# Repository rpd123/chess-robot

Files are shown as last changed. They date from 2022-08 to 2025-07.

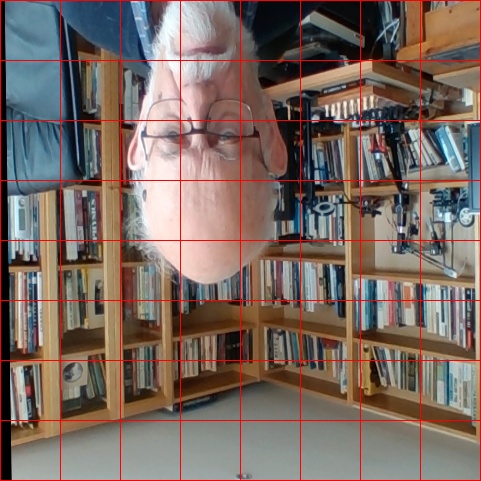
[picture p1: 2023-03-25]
versiongui/images/redlines.jpg

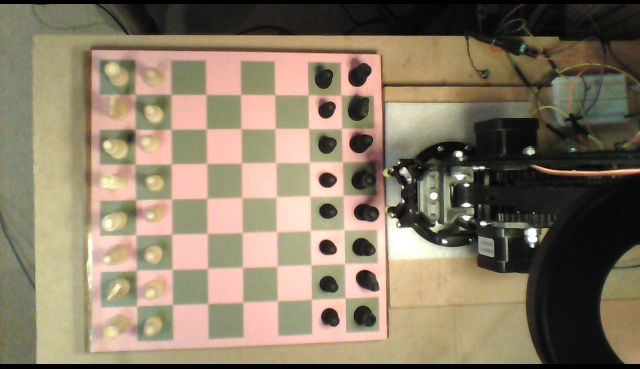
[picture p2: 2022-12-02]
version2/images/1.jpg

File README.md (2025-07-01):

# chess-robot  
  
For the Android/GUI version see the instructions in the versiongui directory.
    
3D printed chess robot, Python code for Raspberry Pi, other Linux or Windows PC. New users should use version 2.

Install Stockfish engine, Python 3, python-pip, espeak

pip install pyserial  
pip install psutil  
pip install numpy  
pip install opencv-python  
pip install stockfish  
pip install pyttsx3  

Run CBint.py from Thonny or elsewhere.

The camera should be positioned directly over the centre of the chess board and lined up pretty well. Then camera calibration asks you to click on the four corners of the playing area of the chessboard (on the image), and you are shown the result. Click them in the order requested. (The robot arm should not be in the way, and all the pieces must be in their correct starting positions). By "playing area" we mean the chessboard squares, NOT including any external margin).

The calibration is remembered even if all systems are shut down, so if the robot, board and camera have not been moved, recalibration can optionally be avoided when a new game is started

The camera should be at least 56 cm above the board. Square size 3.4 cm. Tallest piece: 5.5 cm. The image of a piece should not fall across an adjacent square.

Calibrating the Cartesian robot arm: The lower strut must be vertical and the upper strut horizontal and coming out straight over the board.

Code configuration: You will need to check squaresize, axistorow8, etc. in robotmove.py. Check the declarations in CBstate.py.

Axistorow8 is the distance in mm horizontally along the y coordinate, between the robot’s vertical axis and the centre of row 8. 

The RPi or PC is connected to the Arduino by a USB A/B cable (printer cable). Or alternatively via Bluetooth (not BLE), using an HC-05 Bluetooth module.

Both USB and IP cameras are supported. Calibration for fish-eye distortion is provided, and is more likely to be needed for IP cameras. USB cameras are often OK without it.

Arduino code is at https://github.com/rpd123/Arduino-Firmware 
  
===  
Version1-old only:  
pip install pillow
pip install psutil  
On RPi install fswebcam, aplay

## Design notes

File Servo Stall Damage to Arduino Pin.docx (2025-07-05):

# Servo Stall Damage to Arduino Pin

https://g.co/gemini/share/499b7cfb72a6

Created with 2.5 Pro 4 July 2025 at 16:27 Published 4 July 2025 at 16:36

Is it possible that servo stalling might broke the pin in my arduino mega connected to ramps 1.4 to d4 pin

Google Search

Google Search

Yes, it is possible, though not guaranteed, that a stalling servo could damage the D4 pin on your Arduino Mega connected to a RAMPS 1.4 board. The damage is less likely to be from a direct overcurrent on the signal pin itself, but rather from electrical side effects of the stall.

Here's a breakdown of the potential failure mechanisms:

### How a Stalling Servo Can Damage Your Arduino Pin

When a servo motor stalls, it attempts to draw a much larger current than it does during normal operation. This high current draw, which can be several amps for a standard servo, is the primary source of potential damage. While the servo's power and signal lines are separate, a stall can create conditions that harm the delicate microcontroller pin.

- Ground Potential Difference: This is the most likely culprit. The high stall current flowing through the ground wire of the servo's power supply can cause a significant voltage drop along that ground path. This means the "ground" reference at the servo could be at a higher voltage than the Arduino's ground. This difference in ground potential can expose the Arduino's D4 pin to a voltage level outside its safe operating range, leading to damage. The absolute maximum rating for an Arduino Mega's I/O pin is 40mA, and they are designed to operate at 5V. A sudden surge or a sustained voltage difference can easily exceed these limits.
- Internal Servo Failure: A prolonged stall can cause the servo's internal electronics to overheat and fail. In a catastrophic failure, it's possible for the servo's internal wiring to melt and create a short circuit between the power and signal lines. If the higher voltage from the servo's power supply were to be shorted to the signal line, it would send a damaging amount of current and voltage directly to the Arduino's D4 pin.
- Electrical Noise: The high and erratic current draw of a stalling servo can introduce significant electrical noise onto the power and ground lines. This noise can sometimes manifest as voltage spikes that, if they propagate to the signal line, could be high enough to damage the Arduino pin's sensitive input/output circuitry.

### How the RAMPS 1.4 Connection Plays a Role

The RAMPS 1.4 board provides separate power inputs for the motors and the logic circuits. The servo headers on the RAMPS board, including the one for D4, have pins for signal, 5V power, and ground.

- Shared Power (More Risky): If your servo is being powered directly from the Arduino's onboard 5V regulator (which is common if the D1 diode is installed on the RAMPS board and you are not using an external 5V power supply for the servos), a stall is particularly dangerous. The Arduino's regulator is not designed to handle the high current demand of a stalled servo, which can lead to a voltage drop across the entire 5V rail, affecting the Arduino's operation and increasing the risk of damage to the I/O pins.
- Separate Power (Less Risky): If you are using a dedicated, external power supply for the servos connected to the VCC and ground pins of the servo headers, the risk to the Arduino pin is reduced but not eliminated. The ground potential difference and internal servo failure scenarios can still occur.

### How to Prevent Damage

To protect your Arduino Mega from a stalling servo, consider the following precautions:

- Use an External Power Supply for Servos: Never power more than a single, small servo from the Arduino's onboard 5V regulator. Use a sufficiently rated external power supply for your servos.
- Ensure a Solid Ground Connection: Use thick wires for your ground connections and ensure they are all securely connected to a common ground point to minimize ground potential differences.
- Implement Stall Detection: In your code, you can monitor the servo's position or the current draw (with additional hardware) to detect a stall and cut power to the servo if it doesn't reach its target position within a certain time.
- Add a Current Limiting Resistor: Placing a small-value resistor (e.g., 100-220 ohms) in series with the servo's signal line can offer a degree of protection against small voltage spikes, though it won't protect against a major short circuit.

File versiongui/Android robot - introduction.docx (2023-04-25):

# Chess Robot, 3D-Printed Using Android Phone and Arduino

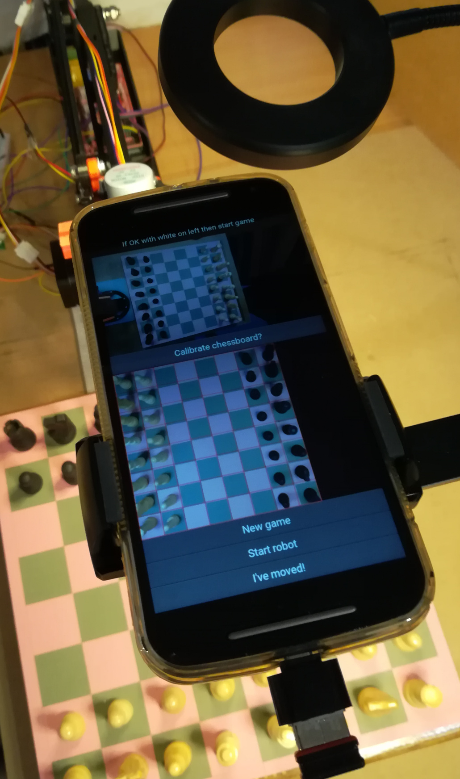
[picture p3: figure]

## Introduction

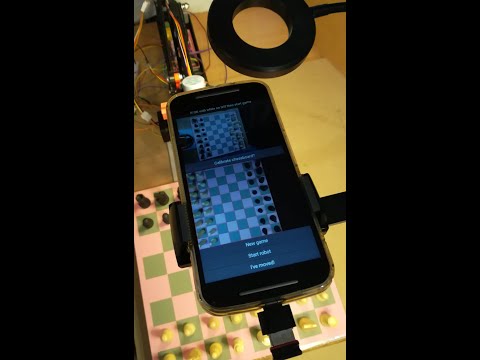
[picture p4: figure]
3D Printed Chess Robot using Android Phone

This chess robot can beat any human!

I previously made a similar 3D-printed chess robot (https://projecthub.arduino.cc/ricpd/3df8bfc4-811c-4ca7-b46a-600d62875669) which makes use of a Raspberry Pi or Windows. That version needs a USB camera, a display screen and keyboard as well as an RPi or Windows processor. Whereas the version described here just needs a discarded Android phone. The phone's camera, microphone and touch screen are used, and the phone is connected to an Arduino via Bluetooth - so no wires come out of the phone.

## Supplies

3D printer

Stepper motor NEMA 17 (x3)

Stepper motor driver board A4988 (x3)

Stepper motor 28BYJ-48 (for grabber)

Stepper driver board ULN2002

Arduino Mega 2560

Ramps 1.4

USB lights (x2)

Spare Android phone (!)

Bluetooth module HC-05

Stand for lights and phone

Wireless mouse and dongle (for chessboard calibration)

Micro USB (or USB-C) OTG to USB Adapter (ditto)

Power supplies

## Requirements

The chess-playing code is written in Python and runs on an Android phone. The code for inverse kinematics and driving the motors runs on an Arduino Mega 2560. A Ramps 1.4 board is attached to the Arduino

The 3D-printed robot is built using STL files.

You will also need a table, lighting and something to hold the phone above the board. And of course, chess pieces and a chessboard. I describe all these things in more detail in the subsequent steps

## How It Works

It works like this:

The human, playing white, makes a move. This is detected by the visual recognition code on the phone. The robot then ponders and then makes its move.

And so on...

Perhaps the most novel thing in this robot is the code for move recognition.

Because the human's move is recognised by a vision system, no special chess board hardware (such as reed switches, or whatever) is needed.

## The Hardware Build

The 3D printer files for the robot are freely available as specified by ftobler here (https://www.thingiverse.com/thing:1718984). Modifications for a longer arm are here (https://www.thingiverse.com/thing:4364030). This is required in order to reach the far corners of the chess board.

We built the cartesian robot (https://projecthub.arduino.cc/ricpd/3df8bfc4-811c-4ca7-b46a-600d62875669), but the SCARA robot (https://projecthub.arduino.cc/ricpd/8bd1b9cd-a719-414a-b0e5-128ca6b6f264) should also work.

In the previous builds we used a special mini-gripper, but this time we used a gripper based on the original ftobler gripper but we modified the files to have longer and thinner fingers, which makes it more suitable for picking up chess pieces. All the STL files for the gripper are here (https://github.com/rpd123/chess-robot/tree/main/stepper%20gripper). The mini-gripper worked with a mini servo motor, but this time we followed ftobler in using a 28BYJ-48 stepper motor.

The stepper motors give very high precision and repeatability.

However, there is a problem with the gripper stepper motor in that when it grips it thinks it has moved to the target position when it hasn't. So when the gripper is opened again it opens to far, and then when closed it doesn't close enough. This is resolved by putting in two screws as endstops for the open position.

The code supports Bluetooth (not BLE), using an HC-05.

The RX output from the HC-05 is connected via a voltage divider to D16 on AUX-4.

The TX output is connected directly to D17 on AUX-4.

https://osoyoo.com/2016/07/03/reprap-3d-printer-circuit-connection-graph/

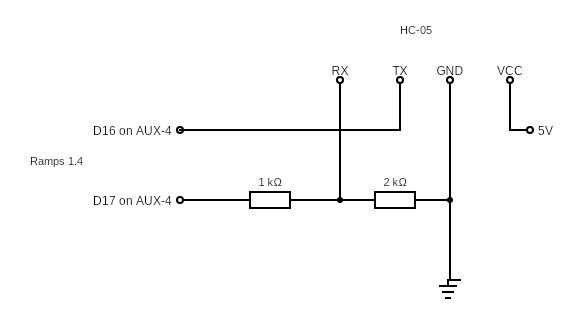
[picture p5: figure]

## The Software Which Moves the Robot

## All the Android code is written in Python 3, and runs on Pydroid 3. The Python files, together with instructions for installing and running can be found here (https://github.com/rpd123/chess-robot/tree/main/versiongui). (This includes instructions for installing Pydroid 3).

So, we then have code which will move pieces, take pieces, castle, support en passant, and so on.

There is a choice of chess engines. If your phone is running Android 7, or if it is rooted, then Stockfish can be used.

Stockfish can beat any human! It is one of the strongest chess engines in the world. It is also much stronger than the best human chess grandmasters.

If your phone is not rooted and it is running a version of Android higher than 7, then Sunfish can be used. It is a simple chess engine - however, it plays at ratings above 2000 at Lichess.

I use some code from chessfortherapy.co.uk to validate the human's move and interact with the chess engine. My code for recognising the human's move and moving the robot arm interfaces with that.

On the Arduino, inverse kinematics code is used in order to move the various motors correctly such that chess pieces can be moved. This code is based on code which ftobler wrote, and can be found via the link above.

## The Software for Recognising the Human's Move

This is similar to the code that I wrote for my previous Cartesian chess robot so please see the description there.

## Other considerations

## The algorithms work best if the chessboard has a colour that is a long way from the colour of the pieces! In my robot, the pieces are off-white and matt black, and the chess board is hand-made using a colour printer onto thin card. It can be seen in the video.

The chessboard should well-lit and evenly lit with minimal shadows from the chess pieces. Light should not be reflected back into the camera from the board or pieces. A sturdy table is needed.

Instructions for calibrating the chessboard and the robot can be found via the first link in the previous section.

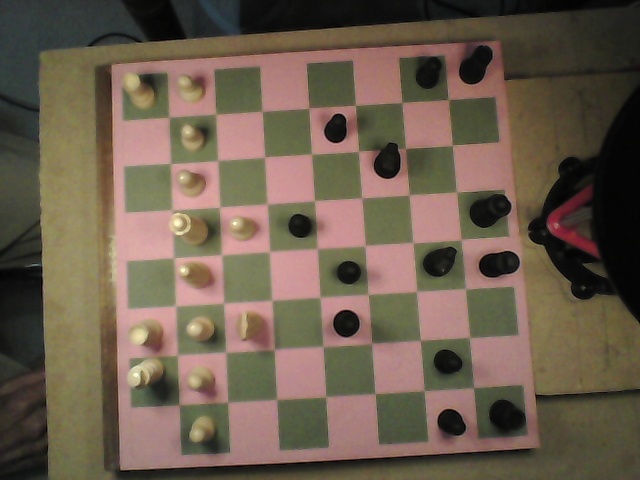
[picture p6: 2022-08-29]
versiongui/images/1copy.jpg

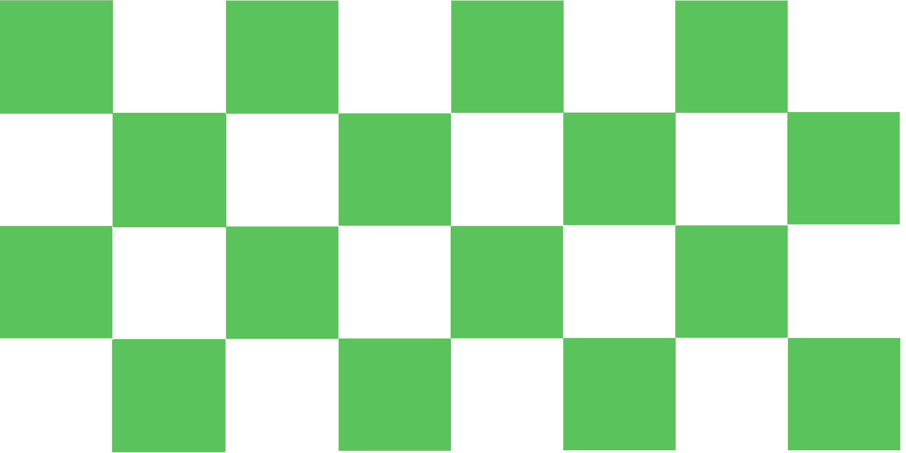
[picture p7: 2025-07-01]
chessboardprint.png

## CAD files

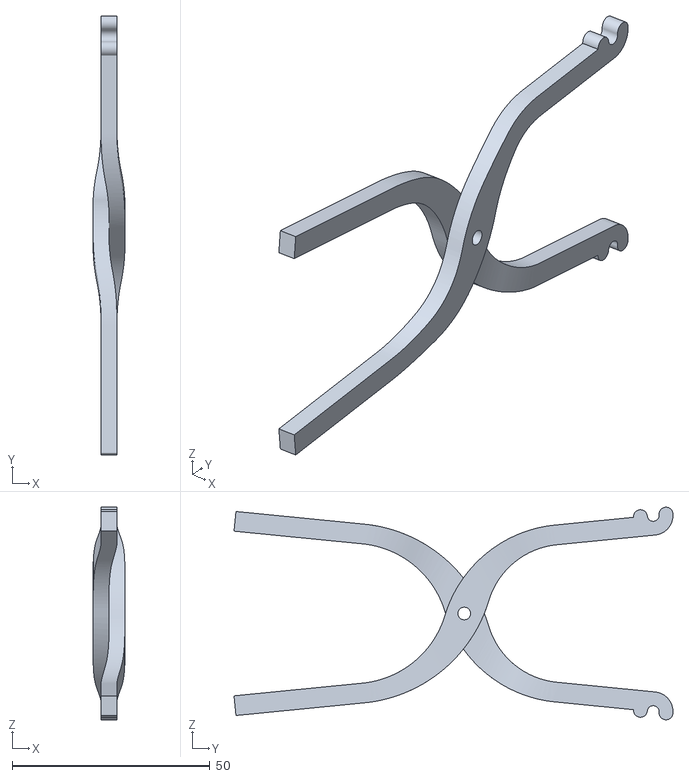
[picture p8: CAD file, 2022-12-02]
another gripper/newgripper-gripper001.0.stl
8.00 x 111.0 x 53.8

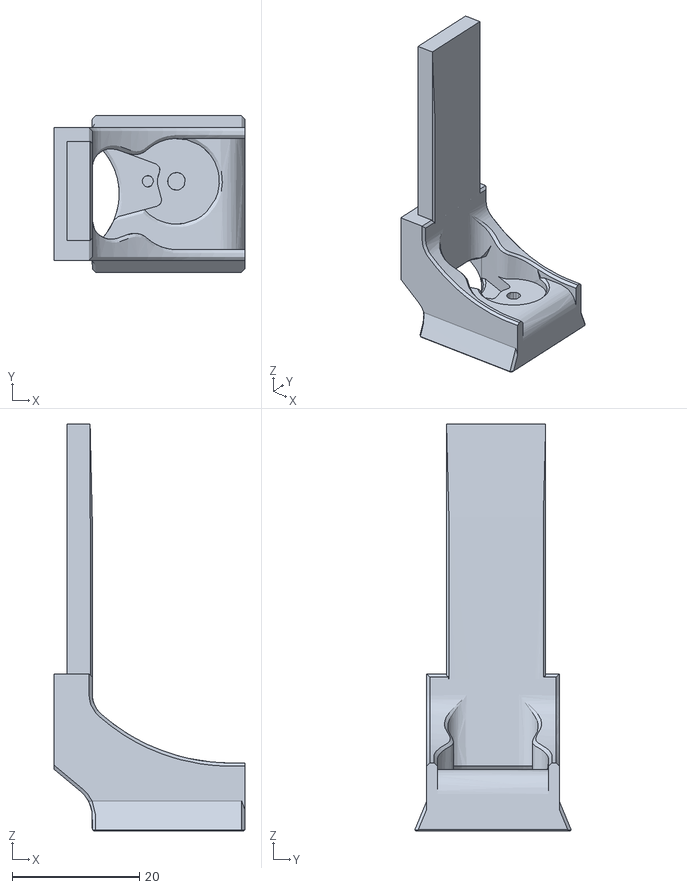
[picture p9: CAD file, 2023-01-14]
stepper gripper/gripperFinger3.stl
30.0 x 24.6 x 64.0

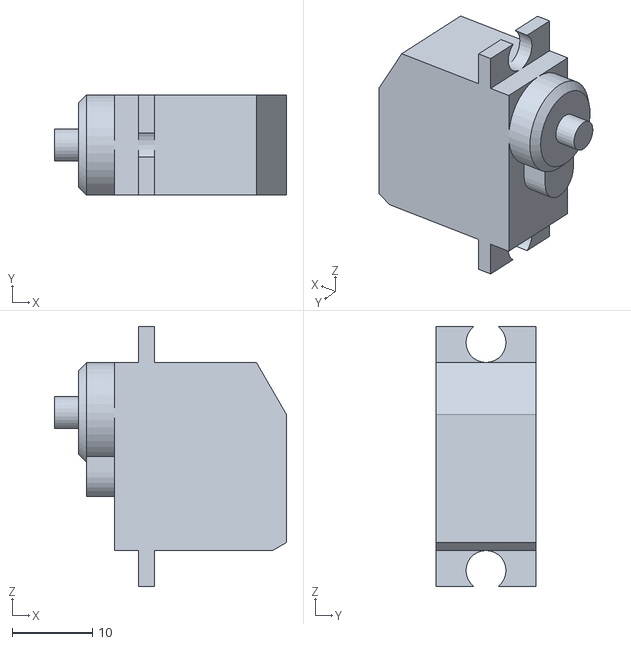
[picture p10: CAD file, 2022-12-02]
another gripper/newgripper-gripper001.1.stl
29.0 x 12.5 x 32.5

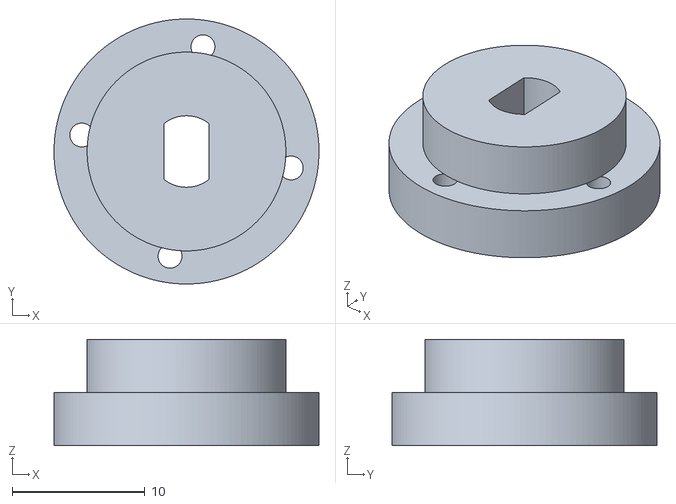
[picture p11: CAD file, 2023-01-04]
stepper gripper/gripper_shaft.stl
20.0 x 20.0 x 8.00

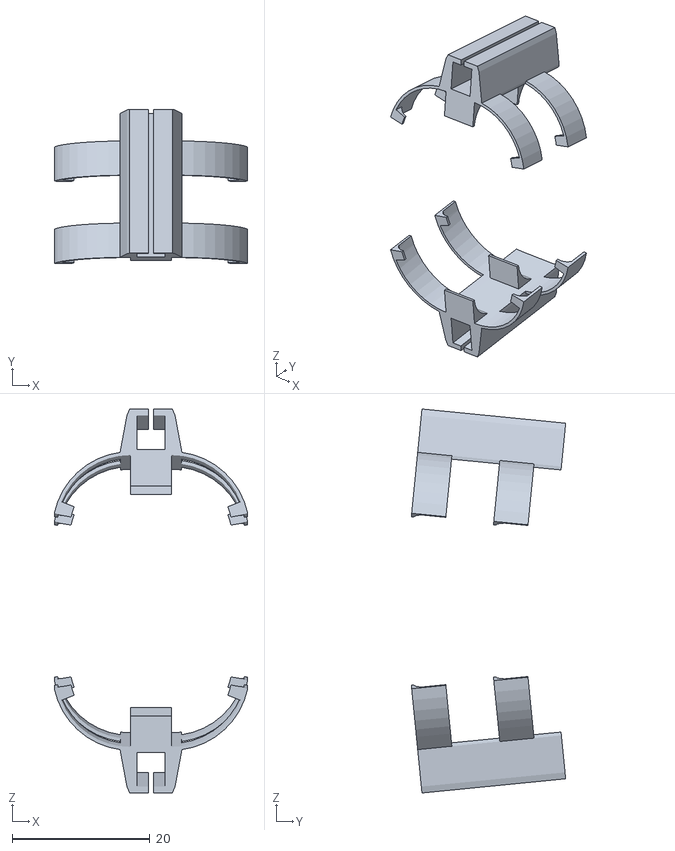
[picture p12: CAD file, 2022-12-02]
another gripper/newgripper-gripper001.3.stl
28.1 x 22.4 x 55.8

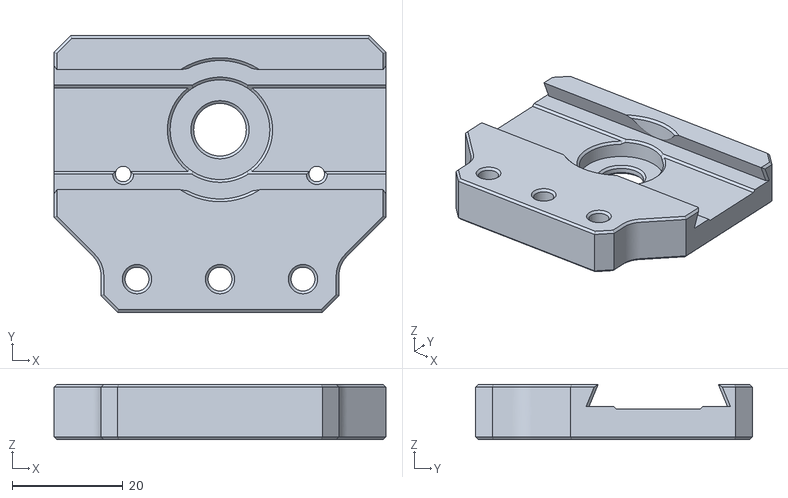
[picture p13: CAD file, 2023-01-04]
stepper gripper/gripperBase_by_ftobler.stl
60.0 x 50.0 x 10.0

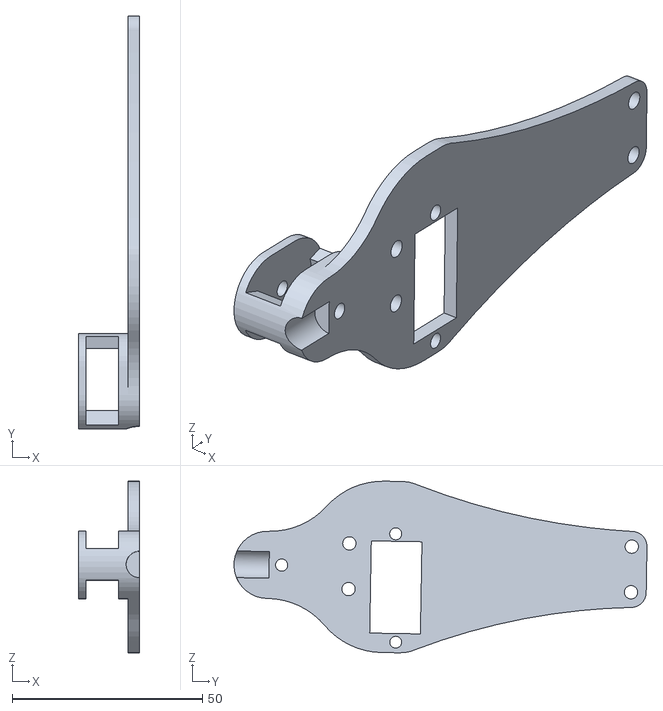
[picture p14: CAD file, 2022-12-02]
another gripper/newgripper-gripper001.4.stl
16.0 x 108.6 x 45.2

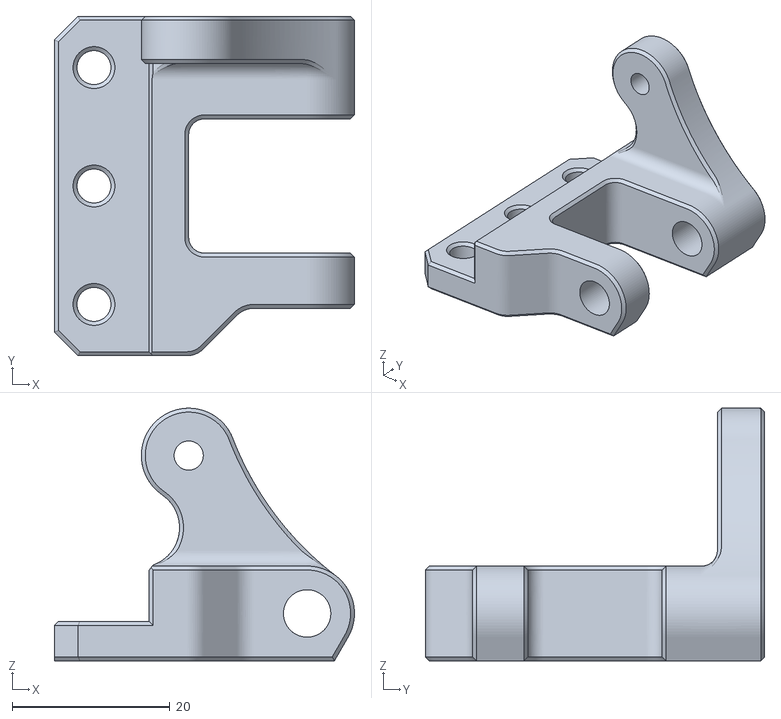
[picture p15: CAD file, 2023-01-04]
stepper gripper/manipulator.stl
38.0 x 43.0 x 32.0

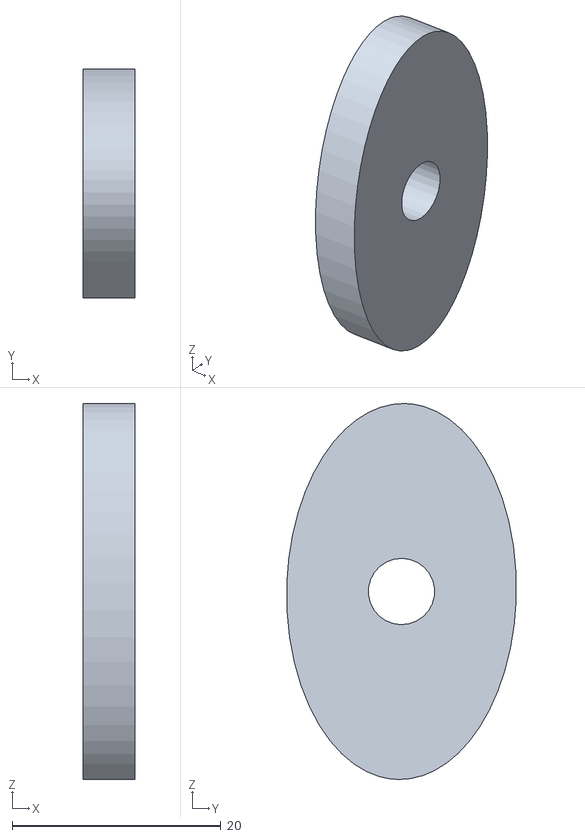
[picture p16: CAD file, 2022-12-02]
another gripper/newgripper-gripper001.2.stl
5.00 x 22.0 x 36.0

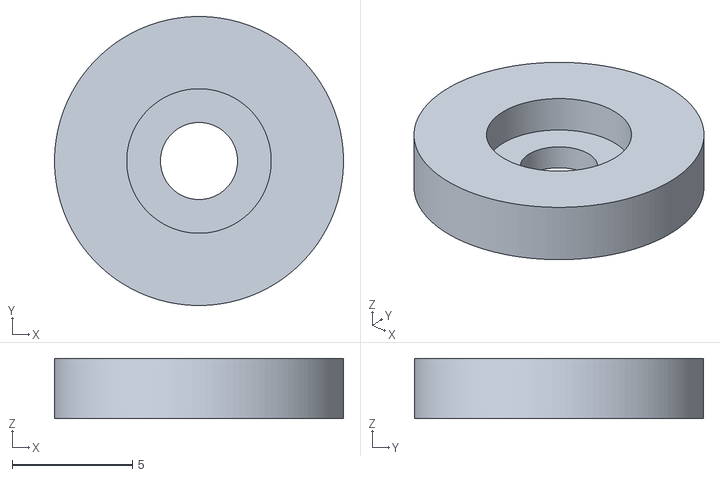
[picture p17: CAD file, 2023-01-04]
stepper gripper/gripper_screw_secure.stl
12.0 x 12.0 x 2.50

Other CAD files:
stepper gripper/gripperHolePlate.stl

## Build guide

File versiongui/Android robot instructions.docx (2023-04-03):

# Android robot instructions

## Installation:

Install from Google Play Store:

Pydroid 3
Pydroid repository plugin
Pydroid Permissions Plugin
Stockfish Engines OEX (if using Stockfish)

Installing Pydroid 3 will automatically install Python3

Open Pydroid 3 and choose “Pip” from the menu. In there you can install Python modules by merely typing their names:

kivy
pyserial
psutil
numpy
opencv-python
plyer

Arduino files are at
https://github.com/rpd123/Arduino-Firmware

After downloading to the PC, use the Arduino IDE to upload them to the Arduino. But before that …

Change two lines in an Arduino library file, which in my case is at:

ProgramFiles(x86)\Arduino\hardware\arduino\avr\cores\arduino\HardwareSerial.h

A couple of lines with buffer size 64 – change to

#define SERIAL_TX_BUFFER_SIZE 128

#define SERIAL_RX_BUFFER_SIZE 128

Pair the phone and the HC-05 if not already paired

Download files for the phone from:

https://github.com/rpd123/chess-robot/tree/main/versiongui

Configuration

Change configuration variables in CBstate.py, robotmove.py and Arduino config.h as appropriate.

Line 5 of config.h should be changed to
#define SERIALX Serial2

when Bluetooth is used.

## Electronics notes

HC-05

The RX output from the HC-05 is connected via a voltage divider to D16 on AUX-4 on the RAMPS.

The TX output is connected directly to D17 on AUX-4.

https://osoyoo.com/2016/07/03/reprap-3d-printer-circuit-connection-graph/

Voltage divider example (Ignore connections to Arduino):

https://electronics.stackexchange.com/questions/280500/why-do-you-have-to-use-a-voltage-divider-with-hc-05-bluetooth-module-arduino

Connections to steppers

Shank1 goes from the shoulder to the elbow, and shank2 goes from the elbow to the gripper.

Connect:

X controller to motor which moves shank2

Y controller to motor which moves shank 1

Z controller to motor which moves the robot vertically

In this diagram
https://github.com/rpd123/community_robot_arm/blob/master/Assembly%20%26%20Control%20Guides/Wiring%20Guide/wiring-lower%20motor.jpg

Controllers are X, Y, Z from left to right.

Note: in this context X, Y, Z refer to motors, not cartesian coordinates.

## Running

Hide the on-screen navigation buttons (if any). (See below).

Have the OTG and wireless mouse dongle in

Open Pydroid3, open main.py and press the yellow button. (Note: NOT CBint.py)

Then you should see “Let’s play chess” at the top of the screen.

This area will be used for messages. The phone is likely to be slow, so at each stage, wait for a new message.

The phone should be positioned directly over the centre of the chess board and lined up fairly well. (The robot arm should not be in the way, and all the pieces must be in their correct starting positions).

Ensure that you can see the whole of the chessboard in the video view. Click on the “Calibrate chessboard” button. A static image will appear below, and a new message.

Using the mouse, click on the corners of the playing area starting at the bottom left. (Note: NOT top left). By "playing area" we mean the chessboard squares, NOT including any external margin.

You should then see the redlines image.

Ensure that you have power to the RAMPS.

Click on Start game, and wait … until it says Game Started.

Click on Start robot and wait.

That button text will change to say “Switch on steppers” Do that.

Button text will change to “Adjust ROBOT placement”. Adjust position of robot base if needed, then press button.

Make a move then press “I’ve moved”

Further info

Once the code is up and running, steppers are on and robot is in home position:

At any time you can put the chess pieces back to the opening position and
Optionally re-calibrate chessboard
Optionally re-calibrate robot
Click on New Game
Then make move

In particular, you can start a new game without re-calibrating the chessboard and without re-calibrating the robot.

You can re-calibrate the chessboard or the robot if the pieces are in the opening position.

If Pydroid is not running
Ensure chess pieces are in the opening position
Open Pydroid, open and run main.py
Optionally calibrate chessboard
Click on New Game
start and calibrate the robot
make move

When the program is closed, the connection to the robot is irretrievably lost, so the robot always has to be re-calibrated when starting from scratch. (But the chessboard does not have to be re-calibrated).

The calibration of the chessboard is retained, so as long as the board, robot and phone have not moved, it is not necessary to re-calibrate the board

Hiding on-screen navigation buttons

This can usually be done via Settings:
https://support.google.com/android/answer/9079644?hl=en

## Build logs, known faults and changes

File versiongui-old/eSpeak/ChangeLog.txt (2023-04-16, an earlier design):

espeak 1.48.04  06.04.2014

Corrections to languages en, nl, ta (rules, list, and dict files).
No other changes from version 1.48.03. No change to program, phoneme
data, or other languages.

espeak 1.48.03  04.04.2014

Fix bug, use of the command-line  "espeakedit --compile" produced phoneme data
in which vowels started at full amplitude instead of gradual increase.

Fix bug:  SSML <break time=""> with values greater than 23 seconds were ignored
due to arithmetic overflow.

Phoneme definition files:
Added new function:  ChangeNextPhoneme().

Language changes include: da, en, fa, gu, hu, it, nl, pt, ta

Started new language: eu (Basque).

*_rules files:
Allow $p_alt1, $p_alt2, etc in pre-conditions.  The rule matches if the
characters before the current point in the word occur as an entry in the
*_list file with the corresponding $alt attibute.

Added condition $list.  This is similar to $p_alt etc, but examines
all words in the *_list file which don't have the $only attribute.

espeak 1.48.01  02.02.2014

*_rules files:
Added rule attribute $noprefix.  The rule is not used if a prefix has been removed from the word.

Windows:
Program changes to enable audio output from Windows DLL.

Language options: 
Added attribute 'dictdialect' to specify en-us voice for words marked with _^_EN.

Superscripts and subscripts are spoken as single letters and numbers during normal speech, and with "superscript" and "subscript" also spoken when spelling.

API: Change function call espeak_TextToPhonemes().

Klatt synthesizer: Fix parallel formant parameters.

Language changes include:
af, an, da, en, fa, ga, gu, hu, hy, it, ml, nl, ta, ur, vi. 

espeak 1.47.10  30.04.2013
  Data change only.
  Revert 't' sound in Spanish to version 1.47.07.

espeak 1.47.09  29.04.2013
  Bug fix (lookup in *_list occasionally found the wrong word).

espeak 1.47.08  26.04.2013

Automatically generate character names for subscript and
superscript characters.

Use internal ctype data for character codes up to U+024F.

Add API function  espeak_TextToPhonemes().

Add test language az, Azerbaijani.

espeak 1.47.07  18.04.2013
Language data changes only.

espeak 1.47.06  15.04.2013
Bug fix for names of non-ascii digits.

RISC OS version:
  Fix for systems which have 44010Hz but not 22050Hz audio.
  Now runs OK in ARMv7 mode.

espeak 1.47.04  02.04.2013

Bug fixes.

Phoneme definitions: add conditions prev2PhW(), next3PhW().

Added language: ms (Malay)

Command line:
  --voices=<directory>  lists the voices in the specified subdirectory.

espeak 1.47.03  21.03.2013

Bug fixes.

espeak 1.47.01  18.03.2013

Added languages:
  an  Aragonese.
  fa  Farsi.
  ga  Irish.
  lt  Lithuanian.
  pa  Punjabi.

Many language improvements, including American English, Danish, Dutch, Portuguese, Tamil.

Command-line program.  Added -version option.

Command-line program.  Added optional value to --ipa option.
  --ipa=1 adds a 'tie' character to link letters in a multi-letter phoneme name.
  --ipa=2 adds a zero-width joiner to link letters in a multi-letter phoneme name.

Command-line program. -X option now lists the names of attributes from *_list files.

Speak the names of Braille Dot characters, U+2800 to U+28FF.

Speak names of characters in some non-native alphabets.

Automatic switch to a different language for text in non-native alphabets.

Improved speaking of text from a non-native alphabet after automatically switching
to a different language voice.

Break words with characters from different alphabets into separate words.

Ignore soft-hyphen (U+00AD) in text.

Klatt vioices, improved nasal vowels.

espeak-data can be compiled using a different sample rate than the default
22050Hz.  eSpeak will then generate speech at that sample rate.

Change the structure of the espeak-data/voices directory to use subdirectories
for europe, asia, and others.

*_rules files.
  Add suffix option 'm' to allow multiplr suffixes to be removed from a word.

*_list files.
  Allow $text attribute when a text translation is given in a different alphabet.

Phoneme definitions.
  Add NOT operator in conditions.
  Add prevVowel() and nextPh2W() 
  Ignore UTF8-BOM sequence at the start of phoneme definition files.

espeakedit application.
  Use wxWidgets 2.8 on Linux.
  Use wxNotebook for prosody and vowel pages.
  Add an option to compile the phoneme data at a specified sample rate (uses the 'sox'
    program for the conversion of WAV file data).

espeak 1.46.01  22.Nov.2011

Added runtime detection of pulseaudio, with fallback to portaudio if pulse is not running.  Use build option "AUDIO=runtime" in the makefile.

Fixed crash on re-initializing libespeak.

SSML.  Commands such as <mark> and <prosody> were ignored if they were inside a multiword group (defined in *_list). Fixed.

SSML. Don't omit <marker> event for words which are recognized as pairs (such as "of the").

SSML: Keep the original voice variant across SSML xml:lang changes.

SSML: Use the original language sub-type (eg. en-sc) when SSML xml:lang changes to a compatible language.

SSML <emphasis>, increase volume for "strong" and "x-strong".

SSML Fix bug where </emphasis> was ignored at end of clause.

SSML: Fix problem where speed can get set to minimum after a <mark> tag.

SSML: Fixed bug where SSML voice change didn't remember an initially specified Klatt variant.

Mbrola:  Add support for voices:  vz1, mx1, mx2.

Mbrola:  Amplitude changes now apply also to mbrola voices.

Mbrola:  "voicing" attribute in mbrola voice files can be sued to adjust the loudness of the mbrola voice.

*_list:  $combine.  Don't combine with the next word if it uses a different language translator.

*_list: $dot attribute was ignored for multi-word entries.

Phoneme definition files. Phoneme programs. Added condition "isTranslationGiven" to test whether a phoneme has been specified explicitly for a word in *_list.

Lang=Hindi:  Suppress some [@] vowels.

Lang=Spanish, fix missing "y" in numbers such as "21".

Lang=EN-US: Don't add 'intrusive r' between phoneme [i@] and a following vowel.
lang=EN-US, distinguish phonemes [aI@] and [aI3] (compare "diet", "tired").

espeak 1.45.04  25.Apr.2011

Added language Malayalam (ml).

lang=de, Fixed important pronunciation error "sage" etc.

Don't speak punctuation names faster at high speeds.

lang=ml, recognise "virama + U+200d" (zero-width joiner) to indicte 'chillu' characters.

Fix problem of punctuation character announcement repeated at the start of the next sentence after speaking is stopped.

Fixed crash due to large numbers of box-drawing characters in text input.

Fixed mbrola phoneme translation of 't' sounds for US-English voices.

espeak 1.45.03  22.Mar.2011

lang=Turkish, fix pronunciation of suffixes, fix suffixes after names.

Windows: command option --stdout caused spurious 0x0d bytes to be included in speech output (CR/LF problem).

Fixed crash which could occur when a clause starts with a hyphen.

espeak 1.45.02  15.Mar.2011

Only use "sonic" speedup above 450 wpm.

lang=Turkish, fix bug, letter uppercase-I-dot was not recognized on Windows.

espeak 1.45.01  14.Mar.2011

Added languages:  Kannada (kn), Georgian (ka)

Many fixes for various languages, including
Danish, Dutch, English, French, German, Hungarian, Russian, Tamil, 

lang=German.  Revert to previous pronunciation of 'r' sounds (from before 1.44).
lang=Esperanto.  Change prosody.

Added "sonic" code (by Bill Cox) to increase the speed of speech after it has been generated by eSpeak.  This removes eSpeak's 450 speed limit.

Command-line options.
Recognize --  which means don't treat following arguments as options.
--help  also gives the path of the espeak-data directory.

SSML
Allow single as well as double quotes around strings.
Fix bugs in SSML "prosody rate".

Mbrola.  Look for Mbrola voices also at /usr/share/mbrola/xx/xx

Fixed bug where double .. was ignored.

Fixed bug in reporting word event lengths in callbacks.

Fixed bug in reporting marker event positions in callbacks, when non-ascii text.

Phoneme definitions.
New keyword "prevoice": always add murmer before a voiced stop, not only after a vowel.
Fixed bug in nextVowel() condition that caused crash.
Fixed bug is condition "isRhotic".

espeakedit.
Try "aplay" and then "play" to play sound.
Improved the Tools->Lexicon functions, which generate **_listx data from a list of words and their pronunciations.

espeak 1.44.04

Fix error in big-endian data conversion program, producing bad data.

Make geminated voiced stops (eg. [bb] ) longer at fast speeds.

Provide conditional compilation of the mbrola interface, define macro INCLUDE_MBROLA in speech.h

Mbrola: also look for mbrola voices in /usr/share/mbrola/voices

Pad TUNES and frame_t structures to a multiple of 4 bytes.

lang=da, Don't weaken unvoiced stops before pause.
lang=el, Remove final unstressed [a] if the next word starts with [a].
lang=pt, Change final [U] to [w] if next word starts with a vowel.

espeak 1.44.03

Fixes:
Lang=el, mk.  Was speaking words as individual letters.
Lang=pl.  Fix prounciation of 'ć' and 'ci'.
Fix crash in big-endian data conversion program.
Fix problem where changing voices reduces the speaking rate, at fast rates.

speak_lib.h:  add macro definitions for minimum, maximum, and normal speaking rate values.

espeak 1.44.01

Fix crash with very long numbers.
Speak very long numbers as individual digits.

Unpronouncable word check:
  Rules for unpronouncable initial letter sequences can now be defined in *_rules files.

  The unpronouncable word check now stops when an apostrophe is found.

Phoneme definitions:
  Optional second parameter to FMT() statement specifies a percentage amplitude.

  Added "ipa" statement to specify the IPA name for a phoneme if the default translation is not correct.

  Add phoneme "equivalents" tables, so that words can be spoken with foreign (eg English) prounuciation rules, but using local phonemes.

  New attributes:  flag1, flag2, flag3

  New attribute: nopause. Prevents the insertion of a short pause when this phoneme starts a word which follows a vowel.

  New conditions: isFlag1, isFlag2, isFlag3, isSibilant.

  New statement: InsertPhoneme()

Phonemes: improve syllablic [m-] [n-] [N-]

Mbrola:
  Command-line espeak and the libespeak library now call the mbrola program directly, rather than producing phoneme text which must be piped into mbrola.

  Added --pho command-line option to generate mbrola phoneme information (.pho data).

Phoneme output:
  Add --ipa command-line option to produce phonemes names using the International Phonetic Alphabet.

  Indicate language changes during phoneme output with: (en)  (fr)  etc.

-X command-line option: Show the matching of multiple-word entries in *_list files.

Speak sequences of letters and dots as individual letters and don't speak 'dot' (eg. "u.s.a").

Don't speak punctuation characters inside <audio> ... <audio/>.

Don't speak "dot" if an ellipsis is followed by a dot.

Vowelcharts:  Show the positions for multiple FMT() statements in a vowel phoneme definition.

*_rules: add attributes  $p_alt $p_alt2 $p_alt3,  $w_alt $w_alt2 $w_alt3

*_list:  add attributes:  $sentence, $atstart

klatt synthesizer: implement echo (defined in voice files).

espeakedit:
  Prosody display: Show stressed and secondary-stress syllables.

  Remember window size and position.

  Change the frame-length field from Spin Control to Text Control to allow better access from screen-readers.

Intonation:
  New file, 'phsource/intonation' to define 'tunes' which can be used from voice files.

  espeakedit: add Compile -> Intonation data

  Intonation: change the internal pitch unit to give finer control, and align with the values displayed in the espeakedit Prosody window.

Speed: Increase range to 80 to 450, with default=175.
Improve speaking at high speeds.

Language options: add an option to the Regressive Voicing option to de-voice the final consonant of words.

lang=ta, hi.  Letter-names for combining vowel characters are distinguished from stand-alone vowel characters by adding an initial click sound.

lang=en: Reduce consecutive unstressed syllables to 'diminished' stress, only in unstressed words.

lang=de: Change 'r' phoneme.

lang=es: Improve the rules for reducing 'b', 'd', 'g' to approximants [B] {D] [Q].

Language improvements include: Danish, Dutch.

espeak 1.43.03  (bug fixes)

Fix crash when embedded control codes are followed by numbers of 5 or more digits.
Fix lang=hu,  First character of an abbreviation is missed after an ordinal number (eg."2. cd")
Fix XML tag not recognized after "..." when announce punctuation is enabled.
Fix lang=zh-yue, 'p' 't' 'k' after a vowel give a long pause.
Fix lang=ru, "o" missing in unstressed syllables.

espeak 1.43.02

Language improvements including Danish.

Fix: "  50000" with leading spaces was spoken as "50".

Don't consider multiple spaces as a thousands separator (eg. "2  000").

Fixed phoneme [n^] for klatt synthesizer.

Lang=Hungarian, don't allow dot as thousands separator.

espeak 1.43

New format for phoneme definitions, including conditional statements for more flexibility.

Added voice variants which use the Klatt synthesizer rather than the eSpeak synthesizer: klatt, klatt2, klatt3

Fixes to the Klatt synthesizer.
Updated phoneme data for use in the Klatt synthesizer.

Allow optional .txt filename suffix for *_rules and *_list files.

HTML tags should not insert a space when they are removed.  This could cause a break inside a word (eg. <b>, <font>).

Fixes to correctly recognise space as a thousands separator in some languages.

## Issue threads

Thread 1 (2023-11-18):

Raspberry pi Pico

JellyBitzGames, 2023-11-18:
Can you use a raspberry pi and a Pico to play chess instead ?

rpd123, 2023-11-19:
> Can you use a raspberry pi and a Pico to play chess instead ?

Would you not also need something in place of the RAMPS 1.4?

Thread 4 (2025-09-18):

First human player move always interpreted as h1g3

DerekCaelin, 2025-09-18:
Despite calibrating the camera, the initial move from the player is misinterpreted.

## Steps to reproduce
1. Run CBint.py and say "yes" to callibration script

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

2. At prompting make first move, `E4` (or any other starting move)

## Expected outcome
Script recognizes move as E4

## Actual outcome
Script recognizes move as h1g3

Output from terminal:

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

## Additional context
I am using a wide-angle lens positioned about 40 cm from the board.

DerekCaelin, 2025-09-19:
I'm using the [Lynxmotion ALD5](https://wiki.lynxmotion.com/info/wiki/lynxmotion/view/ses-v1/ses-v1-robots/ses-v1-arms/al5d/) arm from [your early tutorial.](https://www.instructables.com/Chess-Robot-Raspberry-Pi-Lynxmotion-AL5D-Arm/) I assume that I'll need to use a different set of commands to move the arm, but my first step is to get the script to recognize the state of the board.

rpd123, 2025-09-20:
The updated code is only for the printed arm. You will need to use a green card as described. The camera needs to be at right angles to the board with white on its left.

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

DerekCaelin, 2025-09-21:
Ah! The issue was the orientation of the board. I turned the board 90 degrees to have white on the left hand side of the camera, and it recognized my first move!

My issue is resolved, thank you! Now on to seeing if I can adapt the code that supported the Lynxmotion ALD5 arm.

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

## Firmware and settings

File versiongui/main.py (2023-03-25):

import CBstate
mydir = CBstate.mydir

import CBint
import cv2
#import time
import kivy
kivy.require("1.11.1")
#from kivy.config import Config
#Config.set('graphics', 'width', '1100')
#Config.set('graphics', 'height', '2280')
print(kivy.__version__)
from kivy.app import App
#from kivy.properties import ObjectProperty
#from kivy.uix.widget import Widget
#from kivy.graphics.texture import Texture
from kivy.uix.image import Image
from kivy.uix.button import Button
from kivy.uix.label import Label
#from kivy.uix.scrollview import ScrollView
from kivy.uix.boxlayout import BoxLayout
#from kivy.uix.gridlayout import GridLayout
#from kivy.uix.floatlayout import FloatLayout
from kivy.uix.relativelayout import RelativeLayout
#from kivy.uix.modalview import ModalView
from kivy.graphics import *
#from kivy.clock import Clock
#from kivy.uix.textinput import TextInput

#Config.set('graphics', 'height', '780')
#Config.set('graphics', 'height', '2280')
from kivy.core.window import Window
Window.size = CBstate.windowsize

#from functools import partial
#from kivy.uix.popup import Popup
from kivy.lang import Builder
from kivy.uix.camera import Camera
#from kivy.config import Config
#from plyer import tts
Builder.load_string('''
<CameraClick>:
    orientation: 'vertical'
    spacing: 0
''')
import robotmove as RD
import playermove_rpd as RDpm
#import bluerpd.py
class P(RelativeLayout):
    pass

class MyImage(Image):
    def __init__(self, **kwargs):
        super(MyImage, self).__init__(**kwargs)
        
        #self.start_pos = [0, 0]
        #self.end_pos = [0, 0]
        #self.img_path = mydir+'1.jpg'
       
       
    def dispop(self, myx, myy):
    #def show_popup():
        #global pointscount
        '''
        view = ModalView(auto_dismiss=True,
                         size_hint=(None,None),
                         size=(160, 46),
                         pos_hint={'x': 320 / Window.width, 
                            'y':320 /  Window.height},
                         #pos = (320, 940)
                         )
        '''
        wherenext = ""
        if RDpm.pointscount < 3:
            wherenext = "Now click " + RDpm.whereclick[RDpm.pointscount+1]
        self.parent.ids.toplbl.text = "[" + str(myx) + ", " + str(myy) + "]. " + wherenext
        '''
        vbutton = Button(
            text="[" + str(myx) + ", " + str(myy) + "]" + "\n" + wherenext,
            size=(150,22),
            #text_size  = self.size,
            size_hint =(None, None),
            #halign = "left",
            #pos =(myx, myy),
            background_color=(0, 0, 0, 0))
        view.add_widget(vbutton)
        
        view.open()
        '''
        return
    
    def hidethebutton(self, abutton, *args):
        abutton.text=""
        
    def on_touch_down(self, touch):
        #global mytext
        #rect_size = [10, 10]
        if self.parent.ids.animg.collide_point(*touch.pos):
        #if self.collide_point(*touch.pos):    
            with self.canvas:
                #self.canvas.clear()
                print(self.to_local(touch.x, touch.y, True))
                mydim = int(round(self.parent.ids.animg.size[1]))
                print ("dimensions:")
                print (self.parent.ids.animg.size[0], self.parent.ids.animg.size[1], self.parent.ids.animg.texture_size[0], self.parent.ids.animg.texture_size[1])
                #self.size = (320, 320)
                #self.end_pos = [round(touch.x,2), round(touch.y,2)]
                #print("End pos  :", self.end_pos)
                #mytext = str(self.end_pos)
                #print (mytext)
                #show_popup()
                print ("loc:")
                localisedxy = self.to_local(int(round(touch.x)), int(round(touch.y)), True)
                print(localisedxy)
                self.dispop(localisedxy[0], int(round(mydim - localisedxy[1])))
                ############## Note reveral of y
                #self.parent.ids.toplbl.text = "img height= " + str(self.parent.ids.animg.height)
                #mydim = self.parent.ids.animg.norm_image_size[1]
                
                #mydim = self.parent.ids.animg.texture_size[1]
                
                imgdim = self.parent.ids.animg.texture_size[1]
                RDpm.update_img_dimension(imgdim)
                
                #expander = int(mydim/self.parent.ids.animg.texture_size[0])
                #expanderx = int(expander * CBstate.windowsize[0])
                #expandery = int(expander * CBstate.windowsize[1])
                reductionfactor = imgdim/self.parent.ids.animg.size[1]
                print ("red:")
                print (reductionfactor)
                hstate = RDpm.registerclicks(int(round(localisedxy[0] * reductionfactor)), int(round((mydim - localisedxy[1]) * reductionfactor)))
                #vcallback = self.hidethebutton(vbutton)
                #Clock.schedule_once(partial(self.hidethebutton, vbutton), 0.75)
                if hstate == "finished":
                    #view.dismiss()
                
                    self.parent.ids.toplbl.text = "If OK with white on left then start game"
                    #self.root.ids.animg.source = mydir+'4.jpg'
                    #self.root.ids.animg.reload()
                    
                    print ("img height= " + str(self.parent.ids.animg.height))
                    self.size = (mydim, mydim)
                    self.source = mydir+'redlines.jpg'
                    self.reload()
                    #App.get_running_app().stop()
        else:
            print ("[outside]")
class TouchApp(App):
   
    firstmove = 1
    ccount = 0
    
    def capture(self, btn):
        '''
        Capture the image
        '''
        #Parent.ids['myimg'] = self.img
        self.img.width = CBstate.windowsize[0]
        toptext = "Image captured. Click on bottom left of board below."
        if btn.text == "I've moved!":
            toptext = "Board image captured"
        
        #timestr = time.strftime("%Y%m%d_%H%M%S")
        #self.camera.export_to_png(mydir+"1.png")
        self.camera.texture.save(mydir+"1.png")
        print("Image captured")        
        self.toplabel.text = toptext
        aimg = cv2.imread(mydir+'1.png')
        cv2.imwrite(mydir+'1.jpg', aimg, [int(cv2.IMWRITE_JPEG_QUALITY), 100])
        self.img.source = mydir+'1.jpg'
        self.img.reload()
        #self.remove_widget(self.camera)
        #self.remove_widget(btn)        
        
    def startgame(self, startbtn):
        #self.startrobotbtn.text = RD.startrobotbtntext1
        CBint.fnewgame()
        self.capture(startbtn)            
        imgdim = self.img.texture_size[1]
        RDpm.update_img_dimension(imgdim)        
        
        self.toplabel.text = "Starting game"
        print("Starting game")
        RDpm.dummymove(CBint.chessboard.getBoard())
        self.toplabel.text = "Game started. Start robot"
        print ("Game started")
        
    def startrobot (self, startrobotbtn):
        if self.startrobotbtn.text == RD.startrobotbtntext1:            
            print("Starting robot")
            if CBint.robotinit():
                
                self.toplabel.text = RD.toplabeltext2
                self.startrobotbtn.text = RD.startrobotbtntext2
                print(RD.toplabeltext2)
                #CBint.getboard()
                #CBint.fbmove()
            else:
                self.toplabel.text = "Error: no serial port"
                print("Error: no serial port")
        elif self.startrobotbtn.text == RD.startrobotbtntext2:
            
            RD.init2()# switch on steppers
            self.startrobotbtn.text = RD.startrobotbtntext3
            self.toplabel.text = RD.toplabeltext3
            
            print(RD.toplabeltext3)
        elif self.startrobotbtn.text == RD.startrobotbtntext3:
            RD.gohome()
            self.toplabel.text = RD.toplabeltext4
            self.startrobotbtn.text = RD.startrobotbtntext1
            print(RD.toplabeltext4)
        else:
            print ("Error 17")
            
    def showredlines(self):
        ##
        mydim = int(round(self.img.size[1]))
        self.img.size = (mydim, mydim)
        self.img.source = mydir+'redlines.jpg'
        self.img.reload()        
        ##
        
    def playerhasmoved(self, movebtn):
        self.capture(movebtn)
        ##
        self.showredlines()        
        ##
        if self.firstmove:
            self.firstmove = 0
            #Start the clock
            #Clock.schedule_interval(self.Callback_Clock, 2)
        
        self.toplabel.text = "Player has moved "
        print("Player has moved")
        print (CBint.toplabel)
        self.toplabel.text += CBint.toplabel
        #CBint.getboard()
        CBint.fbmove()
        print (CBint.toplabel)
        self.capture(movebtn)               
        ##
        self.showredlines()        
        ##
        self.toplabel.text = "Computer move: " + CBint.toplabel 
    def Callback_Clock(self, dt):
        self.ccount = self.ccount+1
        print ("Updated %d...times"%self.count)
        RD.receivemsg(sp)
        
    def cameraclick(self, Parent):
        self.orientation = 'vertical'
           
    def clear_canvas(self,obj):
        self.ROI.canvas.clear()
        
    def carryon(self):        
        print ("boo")
        
        return self.img

    def validate_input(self, window, key, *args, **kwargs):
        textfield = self.parent.ids.textfield
        if key == 13 and textfield.focus: # The exact code-key and only the desired `TextInput` instance.
#           textfield.do_undo() # Uncomment if you want to strip out the new line.
            textfield.focus = False
            self.root.ids.lbl.text = textfield.text
#           textfield.text = "" # Uncomment if you want to make the field empty.
            print(textfield.text)
            #self.remove_widget(self.ids['_button'])
            print ("boo")
            #canvas.clear()

            #self.carryon()
            return True
    
    def build(self):
        
        #Window.bind(on_keyboard = self.validate_input)        
           
        Parent = BoxLayout(orientation='vertical',
                           #minimum_height = '8000dp'
                           )
        
        self.toplabel = Label(
            text="Let's play chess!",
            size_hint= (1.0, None),
            font_size = '14sp',
            height= '34dp',
            #width = 300
            )
               
        Parent.ids['toplbl'] = self.toplabel
        Parent.add_widget(self.toplabel)
      
        self.camera = Camera(
            #resolution = CBstate.cameraresolution,
            #resolution = (640, 311),
            #resolution = (960, 540),
            allow_stretch = True,
            keep_ratio = True,
            #height = CBstate.cameraheight,
            size_hint = (0.75,0.75),
            #width = CBstate.windowsize[0], 
            index = CBstate.cameraportno,
            play = True
            )
        Parent.add_widget(self.camera)
        self.btn = Button(
            text = 'Calibrate chessboard?',
            size_hint = (None, None),
            width = CBstate.windowsize[0],
            height = '34dp',
            on_press = self.capture
            )
        
        #self.btn.bind(on_press = self.capture)
        #self.capture(self.btn)
        
        Parent.add_widget(self.btn)
        # end camera
        
        #self.ROI = TouchInput()
        #Parent.add_widget(self.ROI)
        
                # Load Image
        self.img = MyImage(
            #source=mydir + '1.jpg',
            allow_stretch = True,
            nocache=True,
            keep_ratio = True,
            width = CBstate.windowsize[0],            
            size_hint_x = (None),
            opacity = 1
            )
        Parent.add_widget(self.img)
        Parent.ids['animg'] = self.img
        
        self.startbtn = Button(
            text = 'New game',
            size_hint = (None, None),
            width = CBstate.windowsize[0],
            height = '34dp',
            on_press = self.startgame
            )
        Parent.add_widget(self.startbtn)
        
        self.startrobotbtn = Button(
            text = RD.startrobotbtntext1,
            size_hint = (None, None),
            width = CBstate.windowsize[0],
            height = '34dp',
            on_press = self.startrobot
            )
        Parent.add_widget(self.startrobotbtn)
        
        self.movebtn = Button(
            text = "I've moved!",
            size_hint = (None, None),
            width = CBstate.windowsize[0],
            height = '34dp',
            on_press = self.playerhasmoved
            )
        Parent.add_widget(self.movebtn)
        
        return Parent

#import CBint
if __name__ == "__main__":
    TouchApp().run()
    
print ("Finished")

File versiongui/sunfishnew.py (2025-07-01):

#!/usr/bin/env pypy3
from __future__ import print_function

import time, math
from itertools import count
from collections import namedtuple, defaultdict

# If we could rely on the env -S argument, we could just use "pypy3 -u"
# as the shebang to unbuffer stdout. But alas we have to do this instead:
#from functools import partial
#print = partial(print, flush=True)

version = "sunfish 2023"

###############################################################################
# Piece-Square tables. Tune these to change sunfish's behaviour
###############################################################################

# With xz compression this whole section takes 652 bytes.
# That's pretty good given we have 64*6 = 384 values.
# Though probably we could do better...
# For one thing, they could easily all fit into int8.
piece = {"P": 100, "N": 280, "B": 320, "R": 479, "Q": 929, "K": 60000}
pst = {
    'P': (   0,   0,   0,   0,   0,   0,   0,   0,
            78,  83,  86,  73, 102,  82,  85,  90,
             7,  29,  21,  44,  40,  31,  44,   7,
           -17,  16,  -2,  15,  14,   0,  15, -13,
           -26,   3,  10,   9,   6,   1,   0, -23,
           -22,   9,   5, -11, -10,  -2,   3, -19,
           -31,   8,  -7, -37, -36, -14,   3, -31,
             0,   0,   0,   0,   0,   0,   0,   0),
    'N': ( -66, -53, -75, -75, -10, -55, -58, -70,
            -3,  -6, 100, -36,   4,  62,  -4, -14,
            10,  67,   1,  74,  73,  27,  62,  -2,
            24,  24,  45,  37,  33,  41,  25,  17,
            -1,   5,  31,  21,  22,  35,   2,   0,
           -18,  10,  13,  22,  18,  15,  11, -14,
           -23, -15,   2,   0,   2,   0, -23, -20,
           -74, -23, -26, -24, -19, -35, -22, -69),
    'B': ( -59, -78, -82, -76, -23,-107, -37, -50,
           -11,  20,  35, -42, -39,  31,   2, -22,
            -9,  39, -32,  41,  52, -10,  28, -14,
            25,  17,  20,  34,  26,  25,  15,  10,
            13,  10,  17,  23,  17,  16,   0,   7,
            14,  25,  24,  15,   8,  25,  20,  15,
            19,  20,  11,   6,   7,   6,  20,  16,
            -7,   2, -15, -12, -14, -15, -10, -10),
    'R': (  35,  29,  33,   4,  37,  33,  56,  50,
            55,  29,  56,  67,  55,  62,  34,  60,
            19,  35,  28,  33,  45,  27,  25,  15,
             0,   5,  16,  13,  18,  -4,  -9,  -6,
           -28, -35, -16, -21, -13, -29, -46, -30,
           -42, -28, -42, -25, -25, -35, -26, -46,
           -53, -38, -31, -26, -29, -43, -44, -53,
           -30, -24, -18,   5,  -2, -18, -31, -32),
    'Q': (   6,   1,  -8,-104,  69,  24,  88,  26,
            14,  32,  60, -10,  20,  76,  57,  24,
            -2,  43,  32,  60,  72,  63,  43,   2,
             1, -16,  22,  17,  25,  20, -13,  -6,
           -14, -15,  -2,  -5,  -1, -10, -20, -22,
           -30,  -6, -13, -11, -16, -11, -16, -27,
           -36, -18,   0, -19, -15, -15, -21, -38,
           -39, -30, -31, -13, -31, -36, -34, -42),
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
}
# Pad tables and join piece and pst dictionaries
for k, table in pst.items():
    padrow = lambda row: (0,) + tuple(x + piece[k] for x in row) + (0,)
    pst[k] = sum((padrow(table[i * 8 : i * 8 + 8]) for i in range(8)), ())
    pst[k] = (0,) * 20 + pst[k] + (0,) * 20

###############################################################################
# Global constants
###############################################################################

# Our board is represented as a 120 character string. The padding allows for
# fast detection of moves that don't stay within the board.
A1, H1, A8, H8 = 91, 98, 21, 28
initial = (
    "         \n"  #   0 -  9
    "         \n"  #  10 - 19
    " rnbqkbnr\n"  #  20 - 29
    " pppppppp\n"  #  30 - 39
    " ........\n"  #  40 - 49
    " ........\n"  #  50 - 59
    " ........\n"  #  60 - 69
    " ........\n"  #  70 - 79
    " PPPPPPPP\n"  #  80 - 89
    " RNBQKBNR\n"  #  90 - 99
    "         \n"  # 100 -109
    "         \n"  # 110 -119
)

# Lists of possible moves for each piece type.
N, E, S, W = -10, 1, 10, -1
directions = {
    "P": (N, N+N, N+W, N+E),
    "N": (N+N+E, E+N+E, E+S+E, S+S+E, S+S+W, W+S+W, W+N+W, N+N+W),
    "B": (N+E, S+E, S+W, N+W),
    "R": (N, E, S, W),
    "Q": (N, E, S, W, N+E, S+E, S+W, N+W),
    "K": (N, E, S, W, N+E, S+E, S+W, N+W)
}

# Mate value must be greater than 8*queen + 2*(rook+knight+bishop)
# King value is set to twice this value such that if the opponent is
# 8 queens up, but we got the king, we still exceed MATE_VALUE.
# When a MATE is detected, we'll set the score to MATE_UPPER - plies to get there
# E.g. Mate in 3 will be MATE_UPPER - 6
MATE_LOWER = piece["K"] - 10 * piece["Q"]
MATE_UPPER = piece["K"] + 10 * piece["Q"]

# Constants for tuning search
QS = 40
QS_A = 140
EVAL_ROUGHNESS = 15

# minifier-hide start
opt_ranges = dict(
    QS = (0, 300),
    QS_A = (0, 300),
    EVAL_ROUGHNESS = (0, 50),
)
# minifier-hide end


###############################################################################
# Chess logic
###############################################################################


Move = namedtuple("Move", "i j prom")
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

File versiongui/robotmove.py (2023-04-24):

#!/usr/bin/env python
#
# This module copyright 2018, 2022 Richard Day, chess@gotobiz.co.uk
# This code must not be resold, or redistributed in any way without express permission


import CBstate 
mydir = CBstate.mydir
import inversekinematics
import sys
if not CBstate.androidos:
    import pyttsx3
    engine = pyttsx3.init()
    engine.setProperty('rate', 125) # Decrease the Speed Rate
else:
    import bluetrpd
    from plyer import tts
from subprocess import call                         
#import time     # import the time library for the sleep function
from math import sin, cos, atan2, sqrt, atan

import serial
#import bluetoothrpd
axistorow8 = 96  # mm
servoonleft = True
#squaresize = 31    # mm
squaresize = 35 # mm
gripperfloatheight = 60
grippergrabheight = -25 
gripperoffset = 26
openamount = 37 #degrees
closeamount = 2 #degrees
endstops = False
graveyard = "i6"
msgcount = 0

piecewidths = {
    "p": 0,     # degrees
    "r": 3,
    "n": 0,
    "b": 3,
    "q": 4,
    "k": 4
}

if CBstate.steppergripper:
    axistorow8 = 100  # mm
    servoonleft = True
    gripperfloatheight = 57
    grippergrabheight = -14 
    gripperoffset = 53
    openamount = 45 #degrees. Do not change
    closeamount = -55 #degrees
    
    piecewidths = {
        "p": 0,     # additional degrees
        "r": 3,
        "n": 0,
        "b": 3,
        "q": 4,
        "k": 4
    }
# end stepper gripper

if CBstate.SCARA:
    debugrobot = False
    axistorow8 = 35
    gripperfloatheight = 40
    grippergrabheight = -15
    gripperfloatheight = 0  # was 20, do not change
    grippergrabheight = -83  # was -63
    halfway = (gripperfloatheight + grippergrabheight) / 2
    gripperoffset = 0  # indeed!
    openamount = 50 #degrees
    closeamount = 15 #degrees
    #shank1 = 140
    shank1 = 153.0
    shank2 = 161.0    # includes gripper offset
    totalarmlength = shank1 + shank2   # when straight
    elbow = 0
    oldelbow = 0

xmtrans = {
    "a": 3.5,
    "b": 2.5,
    "c": 1.5,
    "d": 0.5,
    "e": -0.5,
    "f": -1.5,
    "g": -2.5,
    "h": -3.5,
    "i": -4.5,
    "j": -5.5
}

xtrans = {
    "a": 0,
    "b": 1,
    "c": 2,
    "d": 3,
    "e": 4,
    "f": 5,
    "g": 6,
    "h": 7,
    "i": 8,
    "j": 9
}
#pieceheights = {
#   "p": 3.2,   # cm
#   "r": 3.6,
#   "n": 3.2,   # grab lower
#   "b": 4.9,
#   "q": 5.7,
#   "k": 6.3
#}
pieceheights = {
    "p": 2.7,   # cm
    "r": 3.0,
    "n": 3.2,   # grab lower
    "b": 4.1,   # 
    "q": 4.6,   # 
    "k": 5.3    # grab lower
}
maxpieceheight = 2.5    # inches

gameresult = ("No result", "Checkmate! White wins", "Checkmate! Black wins", "Stalemate", "50 moves rule", "3 repetitions rule")
lastmovetype = (
    "Normal",
    "En passant available",
    "Capture en passant",
    "Pawn promoted",
    "Castle on king's side",
    "Castle on queen's side")

startrobotbtntext1 = "Start robot"
startrobotbtntext2 = "Switch on steppers"
startrobotbtntext3 = "Adjust ROBOT BASE rotation, then click"

toplabeltext2 = "Steppers are off. Place robot in start position and then switch on steppers"
toplabeltext3 = "Steppers are on. Adjust ROBOT placement, then press button"
toplabeltext4 = "Make move, then press 'I've moved' button"

firsttime = 1
#gtoplabel = ""
sp = 0
send_stream = 0

def waiter(dur):
    #time.sleep(dur)
    pass

def delayarduino(dur):
    return
    gstring = "G4 " + str(dur)
    send_stream.write(gstring.encode())
    
def spflush():
    if CBstate.androidos:
        pass
    else:
        sp.flush()
        
def flushout():
    if CBstate.androidos:
        send_stream.flush()
    else:
        pass
    
def receivemsg(sp):
    global msgcount
    msgcount += 1
    line=""
    if CBstate.androidos:
        #bluetrpd.breceivemsg(sp)
        if sp.ready():
            line=sp.readLine()
            #line = line.decode('utf-8').rstrip() 
            #spflush()
    else:    
        #line=sp.readline().decode('utf-8').rstrip()
        line=sp.read_until().decode('utf-8').rstrip()
        spflush()
    print(msgcount, line)
    
def scaraviastraight(xmm, adjymmint, zmm):
    global elbow, oldelbow
    #print ("elbow: " + str(elbow) + " oldelbow: " + str(oldelbow))
    oldelbow = elbow
    #print ("elbow: " + str(elbow) + " oldelbow: " + str(oldelbow))
    if xmm > 0 and adjymmint < totalarmlength:
        elbow = 0
    
    if xmm > 135:   # parked
        elbow = 0
    
    if xmm < 0 and adjymmint < totalarmlength:
        elbow = 1

    if elbow != oldelbow:
        print ("elbow: " + str(elbow) + " oldelbow: " + str(oldelbow))
        #intermediate move to straight out
        gstring = "G1" + " X0" + " Y" + str(totalarmlength) + " Z" + str(zmm) + "\r"
        print (gstring)
        send_stream.write(gstring.encode())
        receivemsg(sp)
        #input("press enter")

def movearmcoord (xmm, ymm, zmm):  # zmm is height
    receivemsg(sp)
    adjymmint = int(ymm)+axistorow8
    theta = atan2(adjymmint, int(xmm))
    adjxmm = str(int(round(int(xmm) - (gripperoffset*cos(theta)))))   #gripperoffset 0 for SCARA
    adjymm = str(int(round(adjymmint - (gripperoffset*sin(theta)))))  #gripperoffset 0 for SCARA
    if CBstate.SCARA:
        armreach = sqrt((xmm*xmm) + (int(adjymmint)*int(adjymmint)))
        if armreach > totalarmlength:
            print ("Too far away! " + str(armreach))
        #print ((xmm, ymm, zmm))
        scaraviastraight(xmm, adjymmint, zmm)
        
    if CBstate.motorsareservos:
        # A 10 130 120 110 --> Moving the robot Arm with 10ms step time, 130º upper joint angle, 120º lower joint angle and 110º base rotator angle
        # length, height, angle, gripper, wrist angle, wrist rotate
        theangles = inversekinematics.inversekinematics(sqrt((adjxmm * adjxmm) + (adjymm * adjymm)), zmm, 90 + (rtod * (atan(x/y))), 0, -90, 0)
        #theangles: Shoulder, Elbow, Wrist, rotation, g, wr
        gstring = "A 10 " + theangles[1] + " " + theangles[0]  + " " + theangles[3] + theangles[2] + "\r"
        print (gstring)
    else:
        gstring = "G1" + " X" + adjxmm + " Y" + adjymm + " Z" + str(zmm) + "\r"
        print (gstring) ###
    #receivemsg(sp) ####
    #input("Check G-codes then press enter") ###
    spflush()
    #sp.reset_input_buffer()
    send_stream.write(gstring.encode())
    receivemsg(sp)
    #receivemsg(sp) ####
    #input("press enter")

def opengripper(amount):
    adjamount = amount
    if servoonleft:
        adjamount = 90 - amount
    if CBstate.motorsareservos:
        mycode = "G0\r"
    else:
        mycode = "M5 T" + str(adjamount) + "\r"
    print ("Open gripper")
    spflush()
    send_stream.write(mycode.encode())
    receivemsg(sp)
    waiter(0.5)
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

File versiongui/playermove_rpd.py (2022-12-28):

# Vision code

# This module copyright 2018 Richard Day, chess@gotobiz.co.uk
# This code must not be resold, or distributed in any way without express permission

# For each square compute standard deviation and mean of colour values within the square
# Can tell which squares are empty by standard deviation being below a certain value
# After which we distinguish between black (brown) and white because max mean for brown is less than min mean for white

#import time 
#import os
import cv2
import sys
import numpy

#import psutil
#from PIL import Image
import CBstate
mydir = CBstate.mydir
import logging

firsttimeonly = 1
firstgbp = 1
splitwb = 112
splitwbonb = 112
splitwbonw = 112
stdrgb = 23
#squaring = 1 # number of times to look at squaring image


pts_src = numpy.array([[100, 100], [100, 100], [100, 100],[100, 100]])
pts8 = [0,0,0,0,0,0,0,0]
whereclick = ["bottom left", "top left", "bottom right", "top right"]
pointscount = 0
img_dimension = 0

xrevtrans = {
    1: "a",
    2: "b",
    3: "c",
    4: "d",
    5: "e",
    6: "f",
    7: "g",
    8: "h"
}

# Now initialize board arrays
xx, yy = 8, 8;
pieces = [["e" for x in range(xx)] for y in range(yy)]
oldpieces = [["e" for x in range(xx)] for y in range(yy)]
for row in range(2):
    for col in range(8):
        pieces[row][col] = "b"
        oldpieces[row][col] = "b"
for row in range(6,8):
    for col in range(8):
        pieces[row][col] = "w"
        oldpieces[row][col] = "w"   

def updateforcomputermove(board):
    global oldpieces, pieces, firsttimeonly
    if firsttimeonly:
        firsttimeonly = 0
        print ("first time only:")      
    
    else:
        for x in range(8):
            for y in range(8):
                current = board[x][y]
                if current == ".":
                    oldpieces[x][y] = "e"
                elif current.islower():
                    oldpieces[x][y] = "b"
                else:
                    oldpieces[x][y] = "w"
    print ("After computer move:")
    print (oldpieces)
    #raw_input("Now any key")
    
def dummymove(board):
    global firstgbp
    while True:
        firstgbp = 1
        getplayermove (board, ()) # dummy in order to get best number to differentiate between black and white
        #drawredlines()       
        return()    # comment out for testing
        conti = input("Try again? y/n")
        if conti == "n":
            return()
        
def undistort():
    img = cv2.imread(mydir + "1.jpg")
    h,w = img.shape[:2]
    map1, map2 = cv2.fisheye.initUndistortRectifyMap(CBstate.K, CBstate.D, numpy.eye(3), CBstate.K, CBstate.DIM, cv2.CV_16SC2)
    undistorted_img = cv2.remap(img, map1, map2, interpolation=cv2.INTER_LINEAR, borderMode=cv2.BORDER_CONSTANT)
    cv2.imwrite(mydir + "1.jpg", undistorted_img)
    #cv2.imshow("Undistorted", undistorted_img)
    #cv2.waitKey(0)
    ###cv2.destroyAllWindows()
    
def scalefish():
    frame = cv2.imread(mydir + "1.jpg")
    if CBstate.scale_percent != 100:
        width = int(frame.shape[1] * CBstate.scale_percent / 100)
        height = int(frame.shape[0] * CBstate.scale_percent / 100)
        dim = (width, height)  
        # resize image
        frame = cv2.resize(frame, dim, interpolation = cv2.INTER_AREA)        
    cv2.imwrite(mydir + "1.jpg", frame)
    if CBstate.fisheye:
        undistort()

def castling(board, validkingmoves):
    global pieces
    print ("castling code")
    #print (pieces)
    print (validkingmoves)
    if board[7][4] == "K" :
        print ("h1")
        #piecesr = list(zip(*reversed(pieces)))  # rotate
        for (i, j) in validkingmoves:
            tup = (i, j)
            print ("h2", tup)
            if tup == (6,7):
                print ("h3")
                if pieces [7][4] == "e" and pieces[7][5] != "e" and pieces[7][6] != "e" and pieces [7][7] == "e" :
                    print ("castled king side")
                    return ("me1g1")
            if tup == (2,7):
                if pieces [7][0] == "e" and pieces[7][1] == "e" and pieces[7][2] != "e" and pieces [7][3] != "e" and pieces[7][4] == "e" :
                    print ("castled queen side")
                    return ("me1c1")
        return ("")
        
def enpassantmove (board):
    global pieces
    if CBstate.cbstate == 1:    # piece available for en passant
        a = 1
        
def getplayermove(board, validkingmoves):
    global pieces, oldpieces, firstgbp, splitwb, splitwbonb, splitwbonw, stdrgb
    updateforcomputermove(board)
    '''
    print ("Take pic ...")
    if True:
        takepiccv2()
    else:
        os.system('fswebcam -r 640x480 -S 20 --set "Power Line Frequency"="50 Hz" --no-banner --delay 2 --set brightness=25% --set "Exposure, Auto Priority"=False --jpeg 50 --save ' + mydir + '1.jpg')
        #os.system('fswebcam -r 640x480 -S 5 -F 5 --set "Power Line Frequency"="50 Hz" --list-controls --no-banner --delay 1 --set brightness=50% --set "Exposure, Auto"=False --set "Exposure (absolute)"=400 --jpeg 50 --save /home/pi/stepperchessrpd/images/1.jpg')
    #takepic()
    ###im = Image.open(mydir + '1.jpg', 'r')
    #im = im.rotate(90, expand=True)  
    ###crop(im)
    #nudgecrop(im)
   
    homog()
    #cv2.waitKey(0)
    cv2.destroyAllWindows()
    '''
    homolog()
    pix = cv2.imread(mydir + '4.jpg')
        
    h, w, c = pix.shape
    squaresizex = float(w)/8   
    squaresizex = int(round(squaresizex))
    squaresizey = float(h)/8
    squaresizey = int(round(squaresizey))
    
    minRw = minRe = minRb = minGw = minGe = minGb = minBw = minBe = minBb = 256
    minRwonw = minRwonb = minGwonb = minBwonw = 256
    maxRwonw = maxRbonb = 0
    
    maxRw = maxRe = maxRb = maxGw = maxGe = maxGb = maxBw = maxBe = maxBb = 0
    maxRbonb = maxRbonw = 0
    
    minstdp = 256
    maxstde = 0
    
    fudge = 9
    for row in range(8):    
        for col in range(8):
            i = int((row * squaresizex) + fudge)        
            pixlistR = []
            pixlistG = []
            pixlistB = []
            pixlisteR = []
            pixlisteG = []
            pixlisteB = []
            pixlistoR = []
            pixlistoG = []
            pixlistoB = []
            while i < ((row + 1) * squaresizex) - fudge:
                j = int((col * squaresizey) + fudge)
                            
                while j < ((col + 1) * squaresizey) - fudge:
                    pixlistB.append (pix[j,i][0])
                    pixlistG.append (pix[j,i][1])
                    pixlistR.append (pix[j,i][2])
                    if ((i+j) % 2) == 0:    #even
                        pixlisteB.append (pix[j,i][0])
                        pixlisteG.append (pix[j,i][1])
                        pixlisteR.append (pix[j,i][2])
                    else:
                        pixlistoB.append (pix[j,i][0])
                        pixlistoG.append (pix[j,i][1])
                        pixlistoR.append (pix[j,i][2])
                    j += 1
                i += 1
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

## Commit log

2025-07-01 For printing
2025-07-05 Create Servo Stall Damage to Arduino Pin.docx
